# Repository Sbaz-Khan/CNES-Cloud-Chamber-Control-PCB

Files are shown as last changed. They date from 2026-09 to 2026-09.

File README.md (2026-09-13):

# CNES Cloud Chamber Control PCB — ESP32-Based PCB Design

An ongoing **ESP32-based control PCB** developed for the **Concordia Nuclear Engineering Society (CNES) portable diffusion cloud chamber**.

I am serving as the **PCB Design Team Lead** for the project, leading the development of the low-voltage control PCB in **KiCad** and helping translate the overall cloud chamber electronics requirements into a manufacturable board design.

> **Project Status:** In Progress — schematic refinement is nearing completion. Footprint assignment, PCB layout/routing, manufacturing files, and hardware validation are still in development.

---

## Project Overview

A diffusion cloud chamber makes ionizing particle tracks visible by creating a supersaturated alcohol-vapor region above a cooled plate.

The complete CNES system requires several electrical subsystems working together, including:

- Peltier-based cooling
- hot-side and cold-side temperature sensing
- alcohol circulation
- radiator cooling
- chamber illumination
- user controls and display
- electronic regulation of the Peltier cooling stages

The purpose of this project is to develop a **central low-voltage control PCB** that connects these subsystems to an ESP32 and provides the sensing, control, and interface circuitry required by the chamber.

The high-current **24 V Peltier power path remains external to this PCB**. The PCB primarily handles control signals, sensing, user interfaces, and auxiliary 12 V loads.

---

## System Architecture

The cloud chamber uses two main power branches:

- **12 V auxiliary/control branch** — powers the PCB, pumps, fans, LED lighting, and ESP32 power conversion.
- **24 V Peltier branch** — powers two external PSM-292 adjustable buck converters that regulate the two Peltier cooling stages.

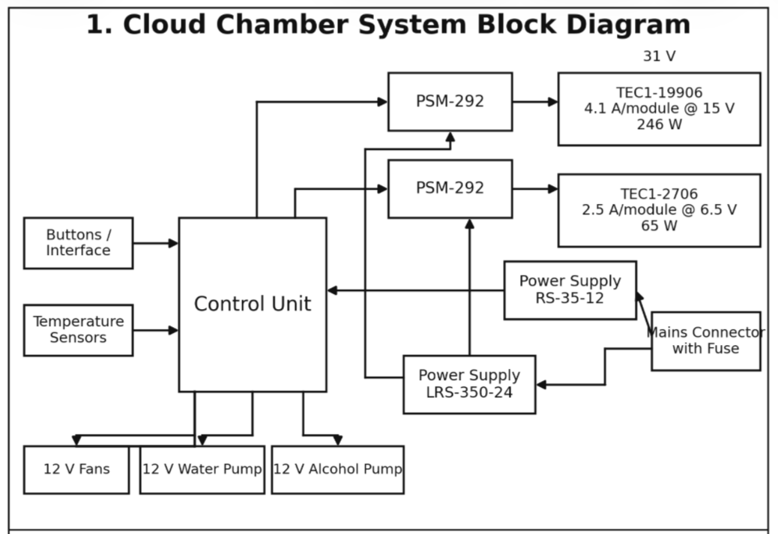
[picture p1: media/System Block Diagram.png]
CNES Cloud Chamber System Block Diagram


*High-level CNES cloud chamber system architecture.*

### Simplified Electrical Architecture

```mermaid
flowchart LR
    AC["Fused / Switched Mains"]

    AC --> PSU12["RS-35-12<br/>12 V Supply"]
    AC --> PSU24["LRS-350-24<br/>24 V Supply"]

    PSU12 --> PCB["ESP32 Control PCB"]
    PSU12 --> AUX["12 V Auxiliary Loads"]

    AUX --> AP["Alcohol Pump"]
    AUX --> WP["Water Pump"]
    AUX --> FANS["Radiator Fans"]
    AUX --> LED["LED Lighting"]

    SENS["Hot & Cold<br/>Thermistors"] --> PCB
    BTN["Start / Reset<br/>Buttons"] --> PCB
    PCB --> OLED["OLED Display"]

    PCB --> DP1["Digital Potentiometer 1"]
    PCB --> DP2["Digital Potentiometer 2"]

    PSU24 --> PSM1["PSM-292 #1"]
    PSU24 --> PSM2["PSM-292 #2"]

    DP1 --> PSM1
    DP2 --> PSM2

    PSM1 --> TEC1["Peltier Stage 1"]
    PSM2 --> TEC2["Peltier Stage 2"]
```

---

## Control Unit Architecture

The ESP32 acts as the central controller for the PCB.

It receives temperature measurements from external thermistors and user inputs from PCB-mounted pushbuttons while controlling or interfacing with the chamber's auxiliary electrical systems.

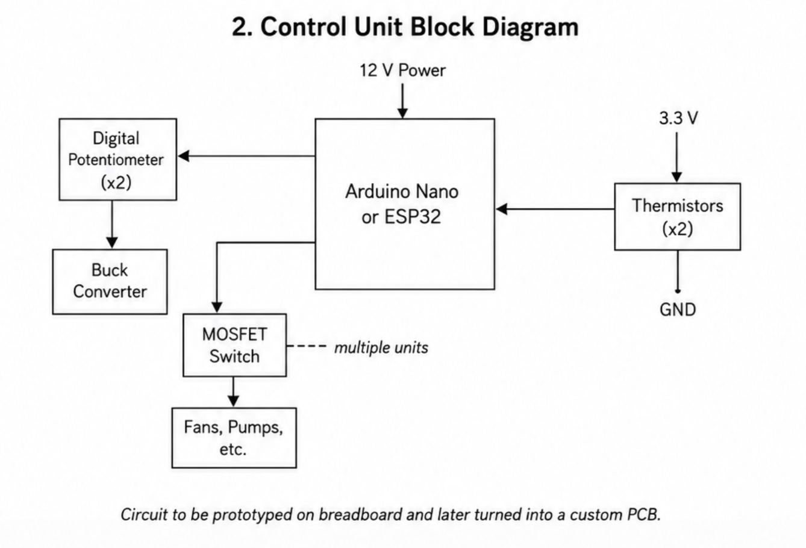
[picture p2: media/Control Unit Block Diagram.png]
CNES Cloud Chamber Control Unit Block Diagram


*Control-unit concept showing sensing, microcontroller control, digital potentiometers, and switched loads.*

---

## PCB Design

The current design uses a **38-pin ESP32 DevKit mounted on two 1×19 headers**, allowing the custom PCB to operate as a carrier/control board.

Using a complete ESP32 DevKit provides built-in:

- USB programming
- voltage regulation
- reset/boot circuitry
- development and debugging support

This reduces implementation risk compared with designing directly around a bare ESP32 device for this prototype.

### Current KiCad Schematic

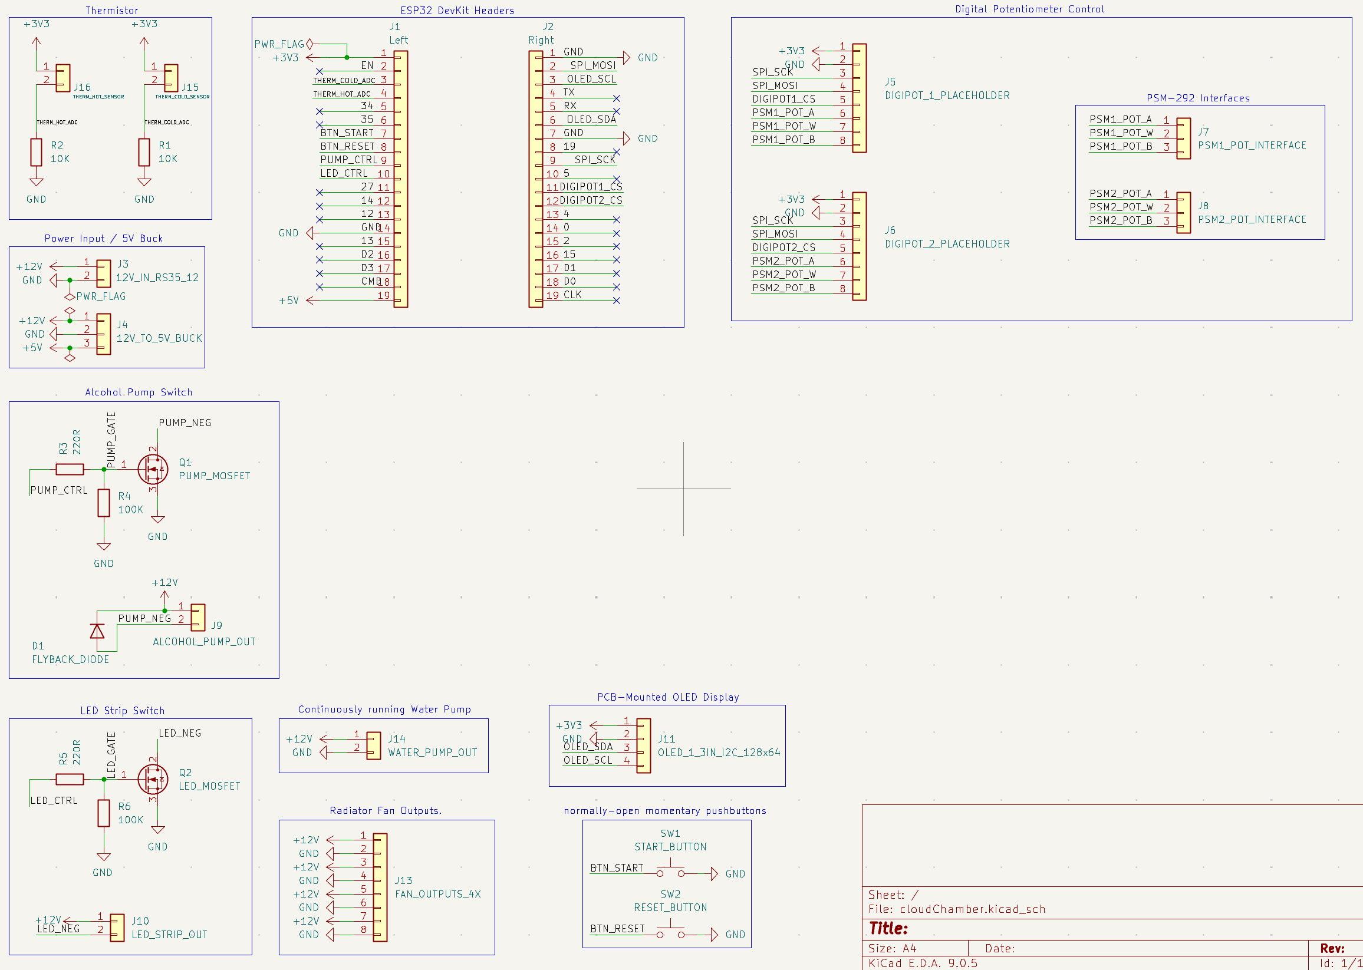
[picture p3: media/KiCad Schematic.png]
CNES Cloud Chamber Control PCB KiCad Schematic


*Current development-stage KiCad schematic for the control PCB.*

---

## Main PCB Subsystems

| Subsystem | Function |
|---|---|
| **ESP32 DevKit Interface** | Central processing and system control |
| **12 V Power Input** | Receives auxiliary power from the RS-35-12 supply |
| **12 V → 5 V Conversion** | Powers the ESP32 DevKit |
| **Thermistor Interfaces** | Measures hot-side and cold-side temperatures |
| **Alcohol Pump Switch** | ESP32-controlled MOSFET switching of the 12 V alcohol pump |
| **LED Strip Switch** | ESP32-controlled MOSFET switching of chamber illumination |
| **Water Pump Output** | Continuous 12 V output for coolant circulation |
| **Radiator Fan Outputs** | Continuous 12 V outputs for radiator cooling fans |
| **OLED Interface** | PCB-mounted I²C display |
| **Pushbuttons** | PCB-mounted Start and Reset controls |
| **PSM-292 Interfaces** | Connections for electronic Peltier-power adjustment |
| **Digital Potentiometer Control** | Planned SPI-based control of the two PSM-292 converters |

---

## Temperature Sensing

Two external **NTC thermistors** are intended to measure:

- cold-side / chamber plate temperature
- hot-side / cooling-system temperature

The physical thermistors are installed at the locations being measured rather than directly on the PCB.

Each thermistor forms a voltage divider with a **10 kΩ fixed resistor** on the control PCB.

```text
+3.3 V
   |
   |
External NTC Thermistor
   |
   +------> ESP32 ADC
   |
 10 kΩ
   |
  GND
```

The ESP32 reads the divider voltage through its ADC and firmware can convert:

```text
ADC Voltage → Thermistor Resistance → Temperature
```

The final thermistor model and temperature-conversion parameters still require confirmation.

---

## Alcohol Pump Control

The 12 V alcohol pump is controlled using a **low-side N-channel MOSFET switch**.

```text
+12 V
  |
Alcohol Pump
  |
  +---- Flyback Diode ----+
  |                       |
MOSFET                     |
  |                       |
 GND ---------------------+
```

The circuit includes:

- logic-level N-channel MOSFET
- 220 Ω gate resistor
- 100 kΩ gate pulldown resistor
- flyback diode for motor inductive transients

The pump is approximately **12 V / 5 W**, corresponding to a nominal current of about:

```text
I = P / V
I = 5 W / 12 V
I ≈ 0.42 A
```

The final MOSFET and flyback-diode part numbers are still being selected.

---

## LED Lighting Control

The chamber lighting is also switched using a low-side N-channel MOSFET controlled by the ESP32.

The LED switching circuit uses:

- logic-level N-channel MOSFET
- 220 Ω gate resistor
- 100 kΩ pulldown resistor

Unlike the alcohol pump, the LED strip does not require a motor flyback diode.

The exact LED strip and its final current requirement are still TBD.

---

## Water Pump & Radiator Cooling

The current design provides continuous 12 V power to:

- the water/coolant circulation pump
- radiator cooling fans

The water pump is currently estimated at approximately **20 W**:

```text
I = 20 W / 12 V
I ≈ 1.67 A
```

Because this is a relatively high-current load for the board, connector type and PCB trace width must be selected accordingly.

The current schematic supports **four 12 V radiator fan outputs**.

---

## OLED & User Controls

The board is designed to support a PCB-mounted:

- **1.3-inch 128×64 I²C OLED**
- **Start button**
- **Reset button**

The buttons are normally-open momentary switches connected between the ESP32 GPIO inputs and ground.

Firmware will use internal pull-ups, giving an active-low interface:

```text
Button Released → HIGH
Button Pressed  → LOW
```

The exact OLED module and mechanical footprint still need to be finalized before PCB layout.

---

## Peltier Power Control

The chamber uses two external **PSM-292 adjustable buck converter modules** to regulate the two Peltier cooling stages.

The planned control architecture is:

```text
ESP32
  |
 SPI
  |
  v
Digital Potentiometer
  |
 A / W / B
  |
  v
PSM-292
  |
  v
Peltier Stage
```

Two digital potentiometer channels are required because the system contains two independently adjustable PSM-292 converters.

The SPI clock and MOSI signals can be shared, while each digital potentiometer uses its own chip-select line.

### Important Design Item

The digital-potentiometer interface is still under development.

Before finalizing this part of the PCB, the following must be verified experimentally:

- original PSM-292 potentiometer resistance
- A/W/B terminal voltages
- terminal current
- compatibility with a digital potentiometer
- safe digital-potentiometer voltage range
- final digital-potentiometer IC
- whether additional protection or interface circuitry is required

The PSM-292 control concept should therefore be considered **planned and under validation**, not finalized.

---

## My Role — PCB Design Team Lead

My responsibility in the CNES cloud chamber project is primarily the development and coordination of the control PCB.

### Contributions to Date

- Leading the PCB design effort for the cloud chamber electronics
- Translating system-level block diagrams and requirements into a KiCad schematic
- Selecting an ESP32 DevKit carrier-board architecture
- Developing the 38-pin ESP32 header and GPIO assignment scheme
- Designing hot-side and cold-side thermistor ADC interfaces
- Designing the alcohol-pump MOSFET switching circuit
- Adding flyback-diode protection for the alcohol pump
- Designing the LED-strip MOSFET switching circuit
- Adding gate resistors and pulldown resistors for controlled MOSFET operation
- Developing 12 V fan and water-pump output interfaces
- Integrating PCB-mounted OLED and pushbutton interfaces
- Developing interfaces for the two external PSM-292 converters
- Planning SPI-controlled digital-potentiometer integration
- Performing KiCad Electrical Rules Checks (ERC)
- Resolving schematic connectivity and power-net warnings
- Coordinating design decisions with the project lead
- Supporting other student team members learning PCB design concepts

The schematic has reached a reported **0 active ERC violations**, although ERC correctness does not replace component compatibility or hardware testing.

---

## Design Development Workflow

The PCB is being developed through the following engineering process:

```mermaid
flowchart LR
    A["System Requirements"] --> B["System Block Diagram"]
    B --> C["Control Architecture"]
    C --> D["KiCad Schematic"]
    D --> E["Component Verification"]
    E --> F["Footprint Assignment"]
    F --> G["PCB Placement"]
    G --> H["Routing"]
    H --> I["DRC + 3D Review"]
    I --> J["Gerber / Manufacturing Files"]
    J --> K["PCB Assembly"]
    K --> L["Hardware Validation"]
```

### Current Position

```text
Requirements
    ↓
Block Diagrams
    ↓
Schematic Design
    ↓
Schematic Refinement      ← CURRENT STAGE
    ↓
Component Selection
    ↓
Footprint Assignment
    ↓
PCB Layout / Routing
    ↓
DRC / 3D Review
    ↓
Gerber Generation
    ↓
Manufacturing
    ↓
Hardware Testing
```

---

## Current Project Status

### Completed / Mostly Completed

- [x] System architecture
- [x] ESP32 DevKit control architecture
- [x] ESP32 GPIO assignments
- [x] thermistor interface circuits
- [x] alcohol pump MOSFET circuit
- [x] LED MOSFET circuit
- [x] water-pump power output
- [x] radiator fan outputs
- [x] OLED interface
- [x] Start / Reset button interface
- [x] PSM-292 A/W/B interface connectors
- [x] schematic ERC cleanup
- [x] 0 active ERC violations at current schematic stage

### In Progress / Remaining

- [ ] finalize digital potentiometer / PSM-292 compatibility
- [ ] select exact digital potentiometer ICs
- [ ] confirm exact ESP32 DevKit mechanical footprint
- [ ] select exact OLED module
- [ ] select final MOSFETs
- [ ] select final flyback diode
- [ ] confirm LED strip specifications
- [ ] confirm radiator fan specifications
- [ ] finalize 12 V → 5 V buck implementation
- [ ] verify complete 12 V system power budget
- [ ] assign PCB footprints
- [ ] perform PCB placement
- [ ] route PCB
- [ ] perform DRC
- [ ] perform 3D mechanical review
- [ ] generate Gerber and drill files
- [ ] prepare BOM / manufacturing files
- [ ] assemble prototype
- [ ] perform hardware validation

---

## PCB Layout Considerations

The upcoming layout stage will include consideration of:

- wider traces for auxiliary 12 V loads
- high-current water-pump routing
- short MOSFET current paths
- flyback diode placement near the pump switching loop
- gate resistors placed close to MOSFET gates
- separation of thermistor analog signals from noisy switching paths
- appropriate connector placement
- ESP32 USB accessibility
- OLED visibility through the enclosure
- pushbutton accessibility
- mechanical mounting holes
- wiring access for pumps, fans, thermistors, and PSM-292 modules
- ground-plane strategy
- enclosure and side-panel clearance

The high-current 24 V Peltier power will **not** be routed through this PCB.

---

## Repository Structure

```text
CNES-Cloud-Chamber-Control-PCB/
│
├── docs/
│   └── Project documentation and design reports
│
├── hardware/
│   └── KiCad schematic and PCB design files
│
├── manufacturing/
│   └── Gerbers, drill files, BOM and fabrication outputs
│
├── firmware/
│   └── ESP32 firmware and control software
│
├── media/
│   ├── KiCad Schematic.png
│   ├── System Block Diagram.png
│   └── Control Unit Block Diagram.png
│
├── README.md
└── .gitignore
```

---

## Tools & Technologies

- **KiCad**
- **ESP32**
- **PCB Design**
- **Schematic Design**
- **Embedded Systems**
- **Power Electronics**
- **Analog Sensor Interfacing**
- **MOSFET Switching**
- **I²C**
- **SPI**
- **Thermistors / ADC Measurement**
- **Git / GitHub**

---

## Planned Hardware Validation

Before a final manufacturing release, critical subsystems will need to be tested and documented.

Planned validation includes:

1. verifying the 12 V and 5 V power paths
2. confirming ESP32 operation
3. checking thermistor ADC measurements
4. testing active-low Start and Reset buttons
5. verifying OLED communication
6. testing alcohol pump switching
7. testing LED switching
8. measuring actual auxiliary-load currents
9. measuring PSM-292 potentiometer terminal characteristics
10. validating the proposed digital-potentiometer replacement
11. checking temperature performance during chamber operation

Measured results will be added to this repository as the project progresses.

---

## Documentation

Detailed design documentation is maintained in the [`docs/`](docs/) directory.

The documentation records:

- design decisions
- subsystem explanations
- electrical calculations
- unresolved design items
- component-selection requirements
- KiCad ERC results
- PCB-layout considerations
- future hardware-validation results

---

## Project Status Notice

This repository documents an **active engineering project**.

The schematic, component selections, PCB layout, and manufacturing outputs may change as testing and design reviews continue.

The PCB has **not yet been manufactured or fully hardware-validated**.

---

## Organization

Developed as part of the **Concordia Nuclear Engineering Society (CNES)** Cloud Chamber project at **Concordia University**.

**Role:** PCB Design Team Lead  
**Focus:** Control PCB architecture, schematic design, subsystem integration, and PCB development

---

## Future Updates

As the project progresses, this repository will be updated with:

- finalized schematic files
- selected component part numbers
- PCB layout
- routed-board screenshots
- KiCad 3D renders
- Gerber files
- BOM
- manufacturing files
- assembled PCB photographs
- test measurements
- cloud chamber integration results

---

*This repository currently represents the schematic-development stage of the CNES Cloud Chamber Control PCB project.*

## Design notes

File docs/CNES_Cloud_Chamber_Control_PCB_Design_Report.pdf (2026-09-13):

# CNES Cloud Chamber Control PCB

### PCB Design Report

Concordia Nuclear Engineering Society Prepared by Sbaz Ali Khan
Design snapshot - 12 September 2026 Revision 0.2

An ESP32 carrier board for temperature sensing, auxiliary load control and the planned electronic adjustment of Peltier power.

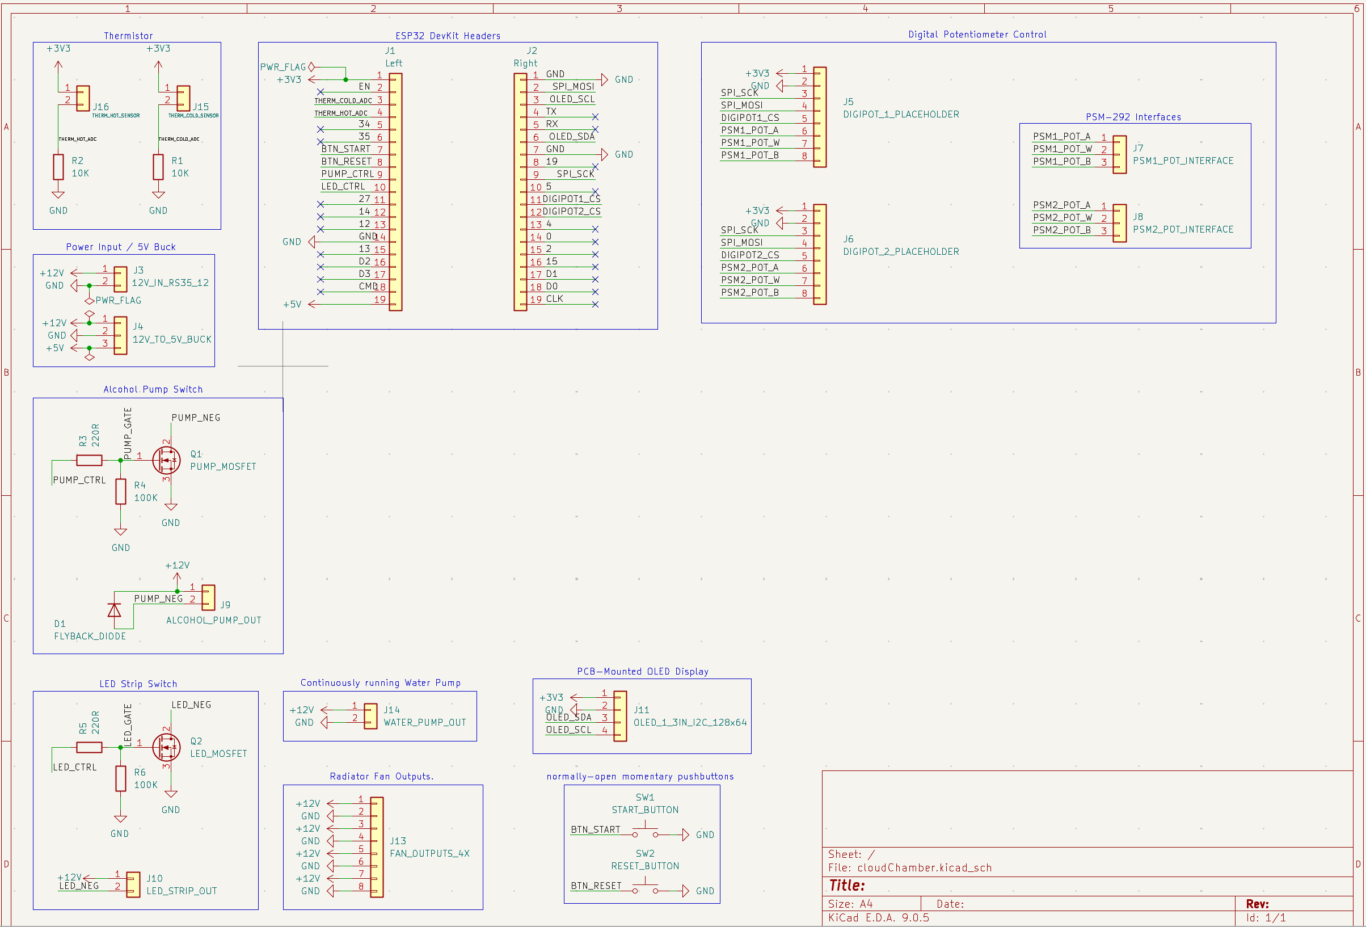
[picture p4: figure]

Current control PCB schematic

Development stage: schematic refinement before footprint assignment and PCB layout.

CNES Control PCB | 12 September 2026

### Table of Contents

# Project objective and current status

The CNES portable diffusion cloud chamber is intended to make ionizing particle tracks visible in supersaturated alcohol vapor above a cooled plate. This work focuses on the development of the low-voltage control PCB that connects temperature sensors, auxiliary loads and the user interface to an ESP32 DevKit.
The current design establishes the carrier-board architecture, pin assignments, thermistor dividers, pump and LED switches, and continuous fan and water-pump outputs. Schematic cleanup reached a reported ERC result of zero active violations. Digital potentiometer compatibility, final component selection, footprint assignment and PCB routing remain to be completed. This report records the design in progress for CNES project continuity and future reference. PCB manufacture and hardware validation remain pending.
The PCB reads hot-side and cold-side temperatures, switches the alcohol pump and bezel lighting, supports an OLED and two buttons, and distributes auxiliary 12 V power. Camera trail classification, permanent count storage and the high voltage clearing field remain broader system functions without finalized implementations on this board. The eventual display requirement includes plate temperature, timer, alpha and beta totals, and counts per minute for each; the initial display focus is cold-plate temperature.
The mains and high-current Peltier paths remain external. The PCB carries auxiliary load current and control signals; it does not route the 24 V Peltier power.

# System architecture

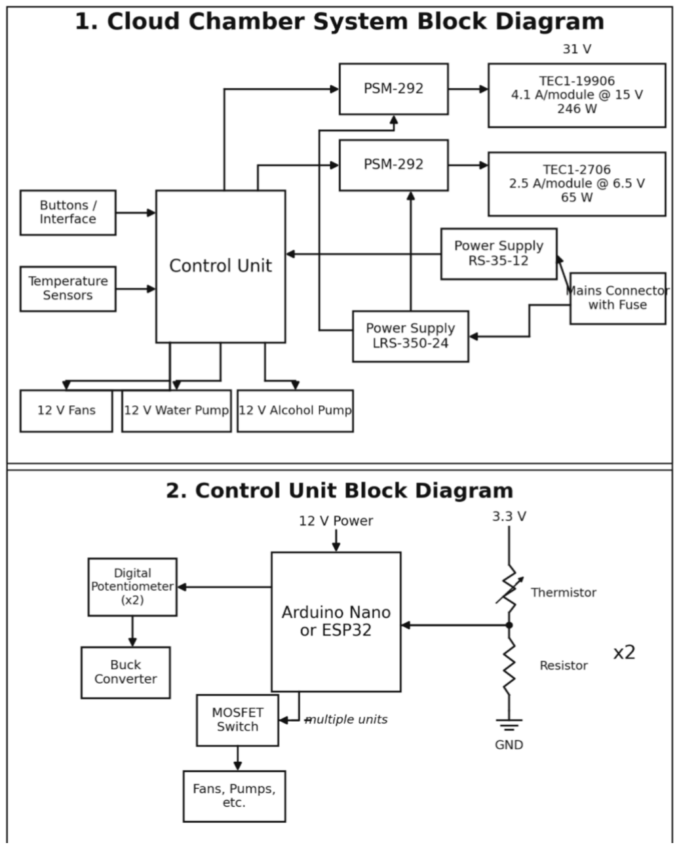
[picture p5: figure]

Figure 1. Overall system block diagram.

The high-level power architecture discussed is:

The fused and switched mains input feeds two separate supplies: the Mean Well RS-35-12 supplies the 12 V auxiliary branch, and the Mean Well LRS-350-24 supplies the 24 V Peltier branch.
The 12 V path powers the control PCB, pumps, fans, LED strip, and a 12 V to 5 V buck stage.
The 24 V path powers the PSM-292 buck converters and Peltier modules. The 24 V / Peltier current is not routed through this PCB.
Known system-level parts from the project/BOM context:
- TEC1-12706 Peltier modules, quantity 4, listed as first-stage Peltier modules
- TEC1-19906 Peltier modules, quantity 4, listed as second-stage Peltier modules
- Mean Well LRS-350-24 power supply, quantity 1, for 24 V Peltier power
- Mean Well RS-35-12 power supply, quantity 1, for 12 V control/auxiliary electronics
- PSM-292 adjustable buck converter modules, quantity 2
- Alcohol pump, 12 V / 5 W, final according to Nathaniel
- Water pump, closer to 20 W according to Nathaniel
- Radiator fans, 120 mm, exact part still not finalized in BOM
- LED strip for bezel, still listed as TBD
- Generic thermistors, quantity 2
- OLED screen and pushbuttons, to be mounted on PCB
- 12 V to 5 V buck converter, exact module/implementation still unresolved

# ESP32 DevKit Header Design

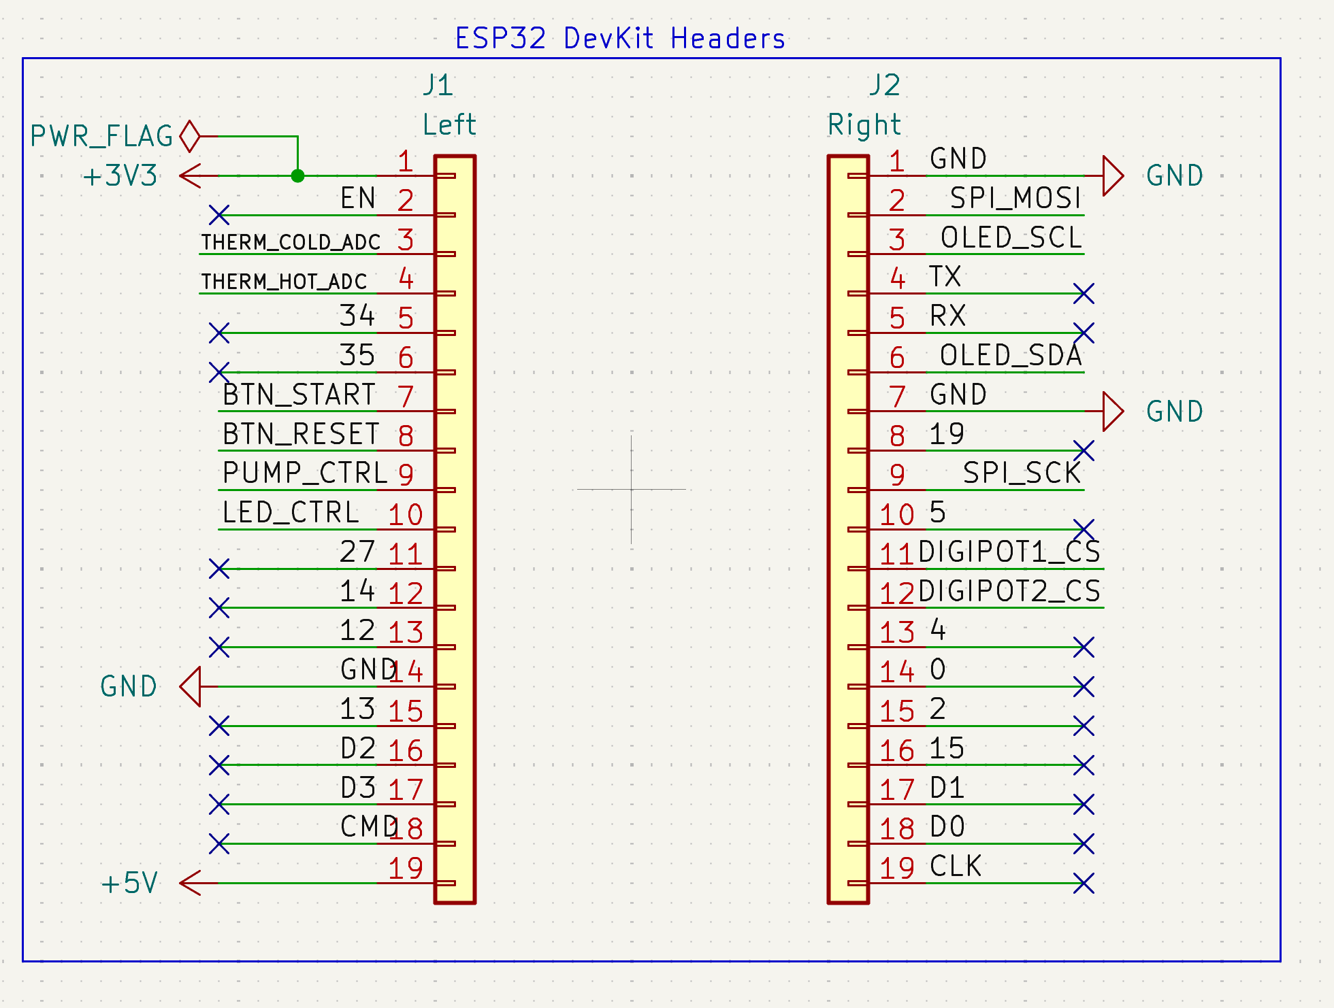
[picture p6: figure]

Figure 2. ESP32 DevKit headers.
The full 38-pin ESP32 DevKit was chosen to reuse its regulator, USB programming, reset and boot support circuits. The carrier uses two 1×19 socket headers; the exact board model, pinout and row spacing must match before layout.
The schematic uses two 1×19 headers:
J1 = ESP32 DevKit left header
J2 = ESP32 DevKit right header
The red numbers in KiCad are connector/header pin numbers. The functional labels correspond to the ESP32 DevKit pinout used during schematic development.

### Used ESP32 pins

ESP32 DevKit pin label | Net name | Function in this PCB
3V3 | +3V3 | 3.3 V logic rail from ESP32 DevKit
5V | +5V | 5 V input to ESP32 DevKit from 12 V to 5 V buck converter
GND | GND | Common ground reference
VP / GPIO36 | THERM_COLD_ADC | Analog ADC input for cold-side thermistor divider
VN / GPIO39 | THERM_HOT_ADC | Analog ADC input for hot-side thermistor divider
GPIO32 | BTN_START | Digital input for start button
GPIO33 | BTN_RESET | Digital input for reset button
GPIO25 | PUMP_CTRL | Digital output controlling alcohol pump MOSFET
GPIO26 | LED_CTRL | Digital output controlling LED strip MOSFET
GPIO21 | OLED_SDA | I2C data line for OLED
GPIO22 | OLED_SCL | I2C clock line for OLED
GPIO23 | SPI_MOSI | SPI data from ESP32 to digital potentiometers
GPIO18 | SPI_SCK | SPI clock for digital potentiometers
GPIO17 | DIGIPOT1_CS | Chip select for digital potentiometer 1
GPIO16 | DIGIPOT2_CS | Chip select for digital potentiometer 2

### Notes on communication pins

GPIO21 and GPIO22 were selected for I2C because they are commonly used as the default ESP32 I2C pins:
GPIO21 = SDA,
GPIO22 = SCL.

The ESP32 can route I2C to other GPIO pins in software, but using the common/default pins keeps the design conventional.
GPIO23 and GPIO18 were selected for SPI:
GPIO23 = MOSI, GPIO18 = SCK.
MISO was not included because the digital potentiometer concept only requires the ESP32 to send commands to the digital potentiometer ICs.
Each digital potentiometer gets its own chip-select line:
DIGIPOT1_CS, DIGIPOT2_CS.
This allows the same MOSI and SCK lines to be shared.

### Unused ESP32 pins

Unused pins were marked with KiCad no-connect flags.
Important pins intentionally avoided:
D0, D1, D2, D3, CMD, CLK: these are typically related to flash memory on ESP32 modules and should not be used for normal project signals.
GPIO0, GPIO2, GPIO12, GPIO15: boot/strapping-sensitive pins, avoided for beginner-safe design. TX and RX: not used because the DevKit handles programming/debug through USB.
EN: not used because the DevKit already has its own enable/reset circuitry.

# Power Architecture

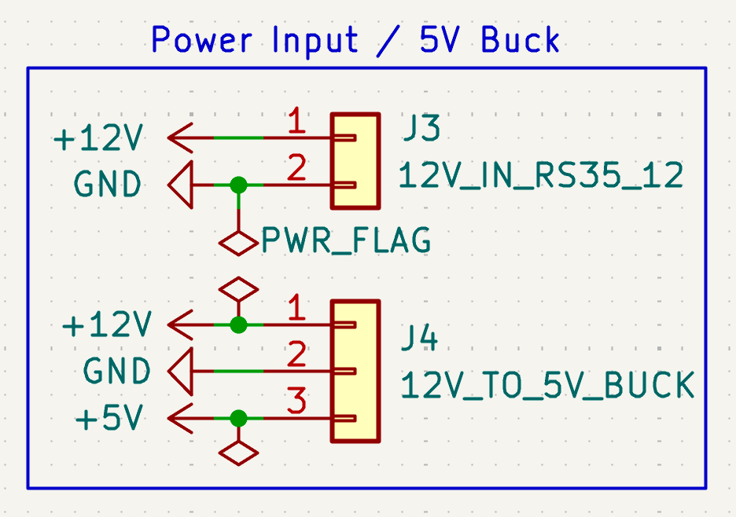
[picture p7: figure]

Figure 3. Power input and 5 V buck stage.

### 12 V input

Connector: J3 = 12V_IN_RS35_12.
Current schematic:
Pin | Net
1 | +12V
2 | GND

This represents the 12 V input from the Mean Well RS-35-12 supply. The RS-35-12 12 V supply powers:
- 12 V to 5 V buck converter
- ESP32 DevKit indirectly through 5 V
- Alcohol pump
- LED strip
- Radiator fans
- Water pump.
Important design concern:
The 12 V supply power budget must be checked once all load currents are finalized. The water pump alone is close to 20 W, or about 1.67 A at 12 V. The alcohol pump is 5 W, or about 0.42 A. Fans, LED strip, and ESP32/buck current must also be included.
Total 12 V current estimate equation:
I_total = I_water_pump + I_alcohol_pump + I_fans + I_LED_strip + I_5V_buck_input
Known calculations:
Alcohol pump: I = P / V = 5 W / 12 V ≈ 0.42 A
Water pump: I = P / V = 20 W / 12 V ≈ 1.67 A.
If the 12 V supply is 3 A, the water pump plus alcohol pump already uses about 2.08 A, leaving limited margin for fans, LED strip, and electronics. This should be checked before final layout.

### 12 V to 5 V buck converter

Connector/block: J4 = 12V_TO_5V_BUCK.
Current schematic:
Pin | Net
1 | +12V
2 | GND
3 | +5V

This represents a buck converter stage that takes 12 V and produces 5 V for the ESP32 DevKit. Unresolved decision:
The buck converter implementation remains to be selected:
a module mounted directly on the PCB or an external buck module wired to the PCB or a fully designed buck converter circuit on the PCB.
This matters because the exact footprint and layout depend heavily on the selected option.

### 3.3 V rail

The ESP32 DevKit provides the +3V3 rail through its onboard regulator.
The PCB uses +3V3 for:
- thermistor dividers
- OLED module logic/power
- digital potentiometer logic, assuming compatible ICs
- possibly other low-voltage logic.
Important constraint:
ESP32 GPIO and ADC pins are 3.3 V logic. Do not apply 5 V or 12 V directly to GPIO/ADC pins.

# Thermistor Subsystem

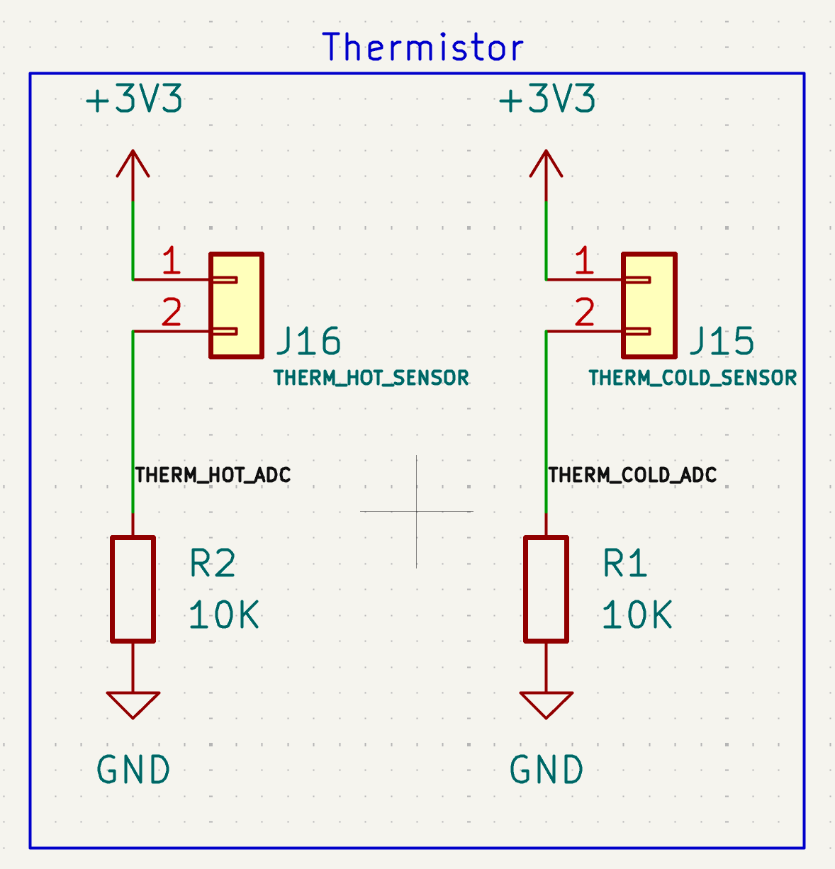
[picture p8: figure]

Figure 4. Thermistor sensor connectors.

### Current revised design

After Nathaniel confirmed the thermistors will be physically mounted on the system, the thermistor symbols were removed and replaced with connectors.
Current connectors:
J15 = THERM_COLD_SENSOR, J16 = THERM_HOT_SENSOR.
Current cold thermistor circuit:
Component/net | Connection
J15 pin 1 | +3V3
J15 pin 2 | THERM_COLD_ADC
R1 | 10 kΩ from THERM_COLD_ADC to GND
ESP32 pin | VP / GPIO36 reads THERM_COLD_ADC

Current hot thermistor circuit:

Component/net | Connection
J16 pin 1 | +3V3
J16 pin 2 | THERM_HOT_ADC
R2 | 10 kΩ from THERM_HOT_ADC to GND
ESP32 pin | VN / GPIO39 reads THERM_HOT_ADC

### Rationale

The ESP32 cannot directly read resistance. It reads voltage on ADC pins.
A thermistor changes resistance with temperature. With the voltage divider, the temperature-dependent resistance becomes a temperature-dependent voltage.
For the current topology:
+3.3 V → external NTC thermistor → ADC node → 10 kΩ resistor → GND
Voltage divider equation:
V_ADC = 3.3 V × R_fixed / (R_NTC + R_fixed)
With R_NTC = 10 kΩ and R_fixed = 10 kΩ:
V_ADC = 3.3 V × 10k / (10k + 10k) = 1.65 V
For a 10 kΩ NTC thermistor:
temperature increases → thermistor resistance decreases → ADC voltage increases temperature decreases → thermistor resistance increases → ADC voltage decreases.
The ESP32 ADC reads the voltage. Firmware then converts:
ADC voltage → thermistor resistance → temperature
The thermistor conversion requires the thermistor’s resistance curve, beta value, or lookup table. The exact thermistor beta value is still unresolved.

# Alcohol Pump MOSFET Switch

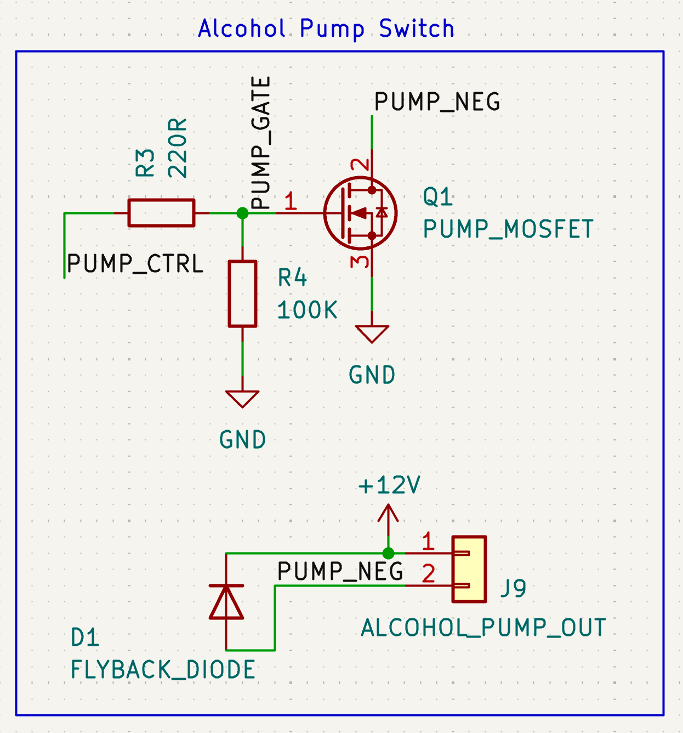
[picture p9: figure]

Figure 5. Alcohol pump MOSFET switch.
The alcohol pump requires on and off control only. No direction reversal is required, so an H-bridge is unnecessary.

### Purpose

The alcohol pump needs to be controlled by the ESP32. The ESP32 GPIO cannot power the pump directly, so a MOSFET switch is used.
The alcohol pump is confirmed as approximately:
12 V, 5 W, current ≈ 0.42 A.
Calculation:
I = P / V = 5 W / 12 V ≈ 0.42 A

### Current schematic

Main components:
Q1 = PUMP_MOSFET
R3 = 220 Ω and R4 = 100 kΩ D1 = FLYBACK_DIODE
J9 = ALCOHOL_PUMP_OUT.
Connector:
J9 pin | Net
1 | +12V
2 | PUMP_NEG

MOSFET connections:

MOSFET terminal | Connection
Gate | PUMP_GATE
Drain | PUMP_NEG
Source | GND

Control signal:
ESP32 GPIO25 → PUMP_CTRL → R3 220 Ω → PUMP_GATE Pulldown:
PUMP_GATE → R4 100 kΩ → GND
Flyback diode:
Diode side | Connection
Cathode/bar side | +12V
Anode side | PUMP_NEG

### Operating principle

This is a low-side N-channel MOSFET switch.
“Low-side” means the MOSFET is placed between the load and ground:
+12V → pump → MOSFET → GND
When PUMP_CTRL is LOW:
gate voltage ≈ 0 V à MOSFET is off àdrain-source path is open, so pump negative side is not connected to ground and pump is off.
When PUMP_CTRL is HIGH:
ESP32 drives gate to approximately 3.3 V à MOSFET turns on and drain-source path conducts so pump negative side connects to ground and current flows through the pump à pump turns on.

### Gate resistor

R3 = 220 Ω
Purpose:
- limits the sudden current spike into the MOSFET gate
- reduces ringing/noise
- limits transient gate-charging current at the ESP32 GPIO
- makes switching cleaner.
The MOSFET gate behaves somewhat like a small capacitor, so the gate resistor slows the sudden charge/discharge slightly.

### Pulldown resistor

R4 = 100 kΩ
Purpose:
- keeps the MOSFET gate at 0 V when ESP32 is booting, resetting, or not actively driving the pin
- provides the intended default-off bias.
The pulldown is called “weak” because 100 kΩ is a large resistance. It gently pulls the gate to ground, but when the ESP32 drives the gate high, the ESP32 easily overrides it.
Default state:
gate = 0 V → MOSFET off

### Flyback diode

The alcohol pump is a motor/inductive load. When switched off, the motor current cannot stop instantly and can create a voltage spike at PUMP_NEG.
The flyback diode gives the leftover motor current a safe loop path.
Normal operation:
+12V side is high and PUMP_NEG side is near ground when MOSFET is on, so the diode is reverse-biased/off.
When the MOSFET turns off:
pump tries to keep current flowing and the PUMP_NEG can spike upward à diode turns on once PUMP_NEG rises above the +12 V side by about a diode drop à current safely circulates through pump and diode à the diode limits the turn-off transient.
The selected diode and MOSFET ratings still require verification.
Important correction made during discussion:
In this low-side switch, the dangerous spike at PUMP_NEG is usually a positive spike, not a negative spike.

# LED Strip MOSFET Switch

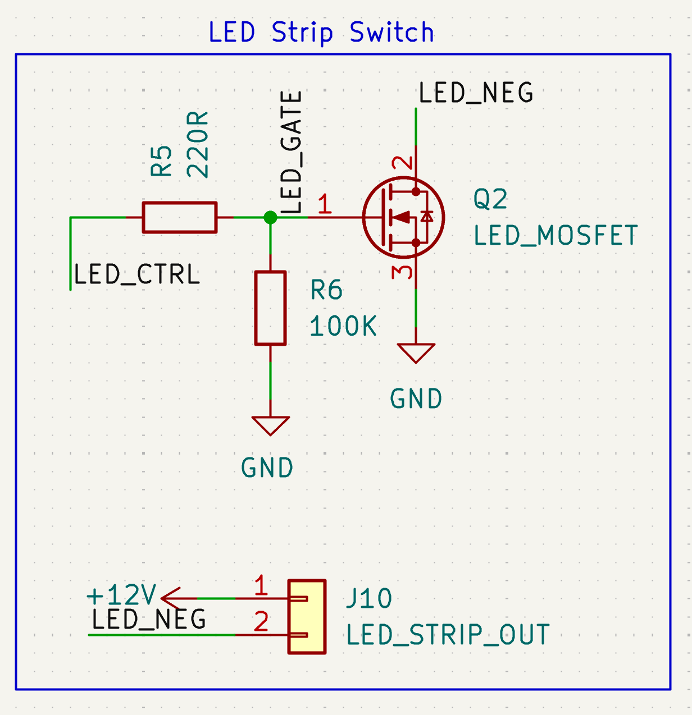
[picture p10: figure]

Figure 6. LED strip MOSFET switch.

### Purpose

The LED strip is controlled by the ESP32 using a MOSFET switch.
The LED strip is intended to illuminate the chamber, so particle tracks are visible.

### Current schematic

Main components:
Q2 = LED_MOSFET, R5 = 220 Ω, R6 = 100 kΩ, J10 = LED_STRIP_OUT. Connector:
J10 pin | Net
1 | +12V
2 | LED_NEG

MOSFET connections:

MOSFET terminal | Connection
Gate | LED_GATE
Drain | LED_NEG
Source | GND

Control signal:
ESP32 GPIO26 → LED_CTRL → R5 220 Ω → LED_GATE Pulldown:
LED_GATE → R6 100 kΩ → GND

### Operating principle

Same as the alcohol pump switch, but without the flyback diode.
When LED_CTRL is LOW:
MOSFET off à LED negative side not connected to ground à LED strip off.

When LED_CTRL is HIGH:
MOSFET gate ≈ 3.3 à MOSFET on à LED negative side connects to ground à current flows: +12V → LED strip → MOSFET → GND à LED strip on.

### Why no flyback diode

The LED strip is not a motor/inductive load, so it does not require a flyback diode like the pump.

# MOSFET Selection Requirements

The schematic currently uses generic N-channel MOSFET symbols for Q1 and Q2.
These are not final part numbers.
The final MOSFETs must be:
N-channel, logic-level, fully enhanced with 3.3 V gate drive, rated for the load current with margin, rated for at least the relevant voltage, preferably 30 V or more for 12 V loads and low RDS(on) at VGS = 2.5 V or VGS = 3.3 V.
Important clarification:
VGS (th) is not enough. Gate threshold voltage only means the MOSFET barely starts to turn on. It does not mean the MOSFET can carry the load current efficiently.
Need to check:
RDS (on) specified at low gate voltage.
RDS (on) means drain-source resistance when the MOSFET is on. Lower RDS (on) means less heat. MOSFET heat estimate:
P_MOSFET ≈ I² × RDS (on)
This will be useful when choosing the final MOSFETs after load currents are known.

# Water Pump Output

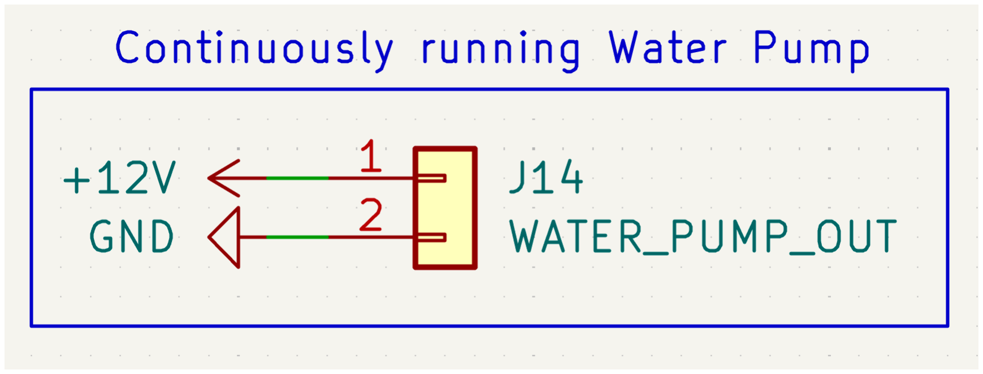
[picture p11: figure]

Figure 7. Continuous water pump output.

### Purpose

The water pump circulates coolant/water in the hot-side cooling loop. It is not for putting water into the chamber.
The water loop carries heat away from the hot side of the Peltier modules to the radiator.

### Current design

Current decision: water pump runs continuously.
Connector:
J14 = WATER_PUMP_OUT.
Current schematic:
J14 pin | Net
1 | +12V
2 | GND

No MOSFET control is used for the water pump.

### Power and current

Nathaniel stated the water pump draws closer to 20 W.
At 12 V: I = 20 W / 12 V ≈ 1.67 A
Based on Nathaniel’s rule, this should use a screw terminal because it is above 1 A.

# Radiator Fan Outputs

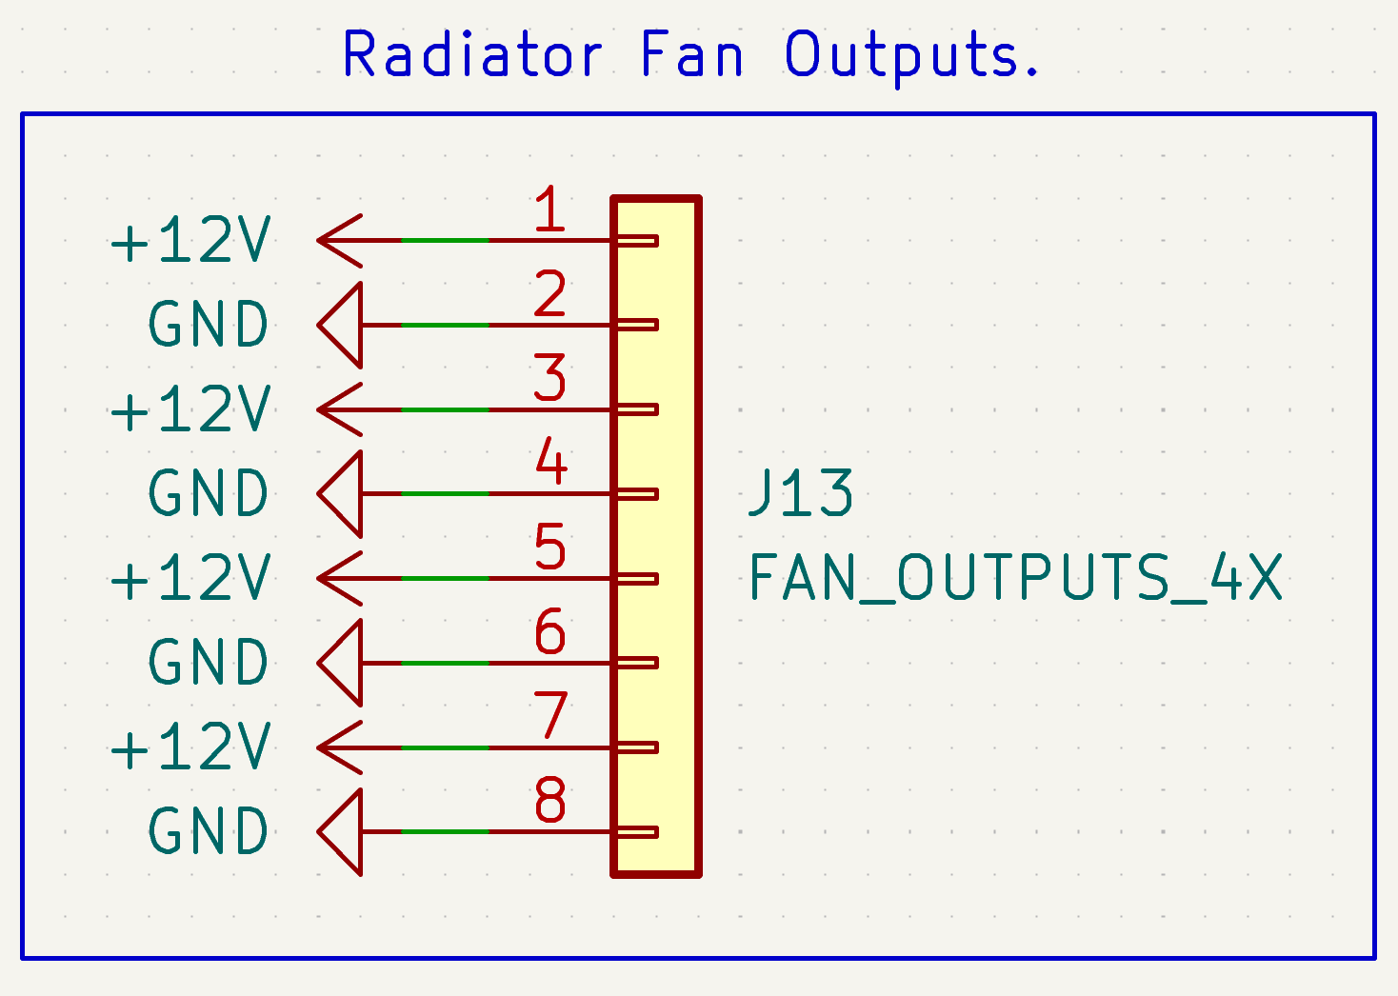
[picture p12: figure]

Figure 8. Radiator fan outputs.

### Purpose

Fans cool the radiator. The water loop carries heat from the Peltier hot side to the radiator, and fans blow air through the radiator to dump that heat into room air.
Cooling chain:
Heat passes from the cold plate through the Peltier stack into the water block. The water pump circulates coolant to the radiator, where the fans reject heat to ambient air.

### Current schematic

Connector:
J13 = FAN_OUTPUTS_4X.
Current schematic supports four 12 V fan outputs:
Fan | Pins
Fan 1 | pin 1 = +12V, pin 2 = GND
Fan 2 | pin 3 = +12V, pin 4 = GND
Fan 3 | pin 5 = +12V, pin 6 = GND
Fan 4 | pin 7 = +12V, pin 8 = GND

Current decision: fans run continuously from 12 V.
No MOSFET control is included for fans.

# OLED Display Subsystem

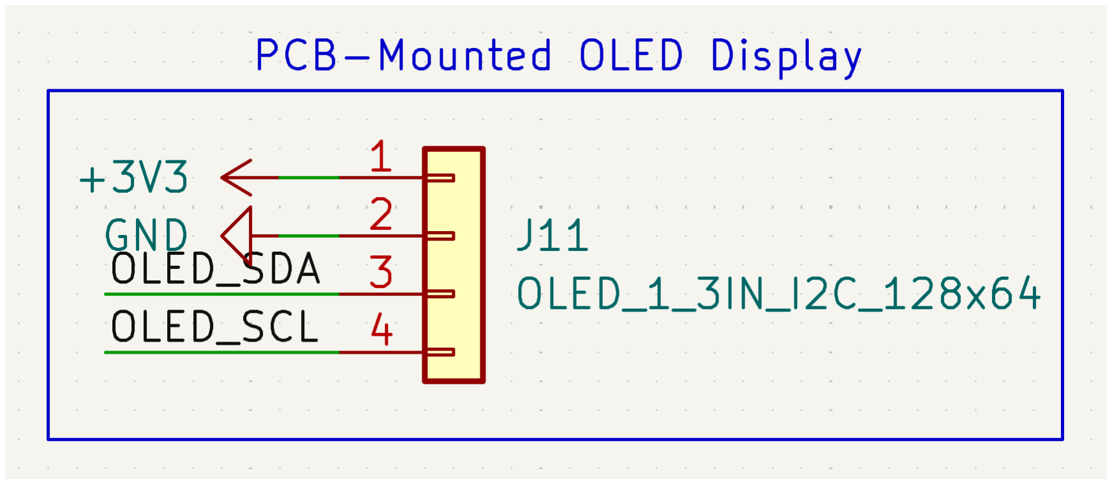
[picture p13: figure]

Figure 9. PCB mounted OLED interface.

### Revised design

Nathaniel said the PCB is mounted on one of the side panels, so the OLED and buttons can be directly on the PCB. The OLED design was updated to be PCB-mounted.
Current connector/module interface:
J11 = OLED_1_3IN_I2C_128x64.
Current schematic:
J11 pin | Net
1 | +3V3
2 | GND
3 | OLED_SDA
4 | OLED_SCL

The schematic block was renamed:
PCB-Mounted OLED Display.

### OLED selection direction

A 2-inch OLED was considered, but concern was raised that larger OLEDs are more likely to use SPI or have more complex pinouts. To minimize schematic changes and keep the design simple, the direction was changed back to:
1.3-inch; 128×64 pixels; I2C interface; 4-pin module; 3.3 V-compatible.
Reason:
1.3-inch 128×64 I2C OLED modules are common and fit the current simple 4-wire design.

### Important OLED warning

The electrical schematic can remain as 4 pins, but the exact OLED module must be selected before layout because modules may differ in:
pin order, module board size, mounting hole spacing, header orientation, voltage requirement, I2C vs SPI interface etc.
Some modules may order pins as VCC, GND, SCL, SDA instead of VCC, GND, SDA, SCL. The final footprint must match the actual module.

### Assembly note

PCB-mounted does not automatically mean the manufacturer will solder the OLED module during PCB fabrication.
There are two cases:
Bare PCB order: OLED is soldered/mounted manually later
PCBA order: manufacturer assembles it only if the part/module is included and supported. This decision is still not finalized.

# Button Subsystem

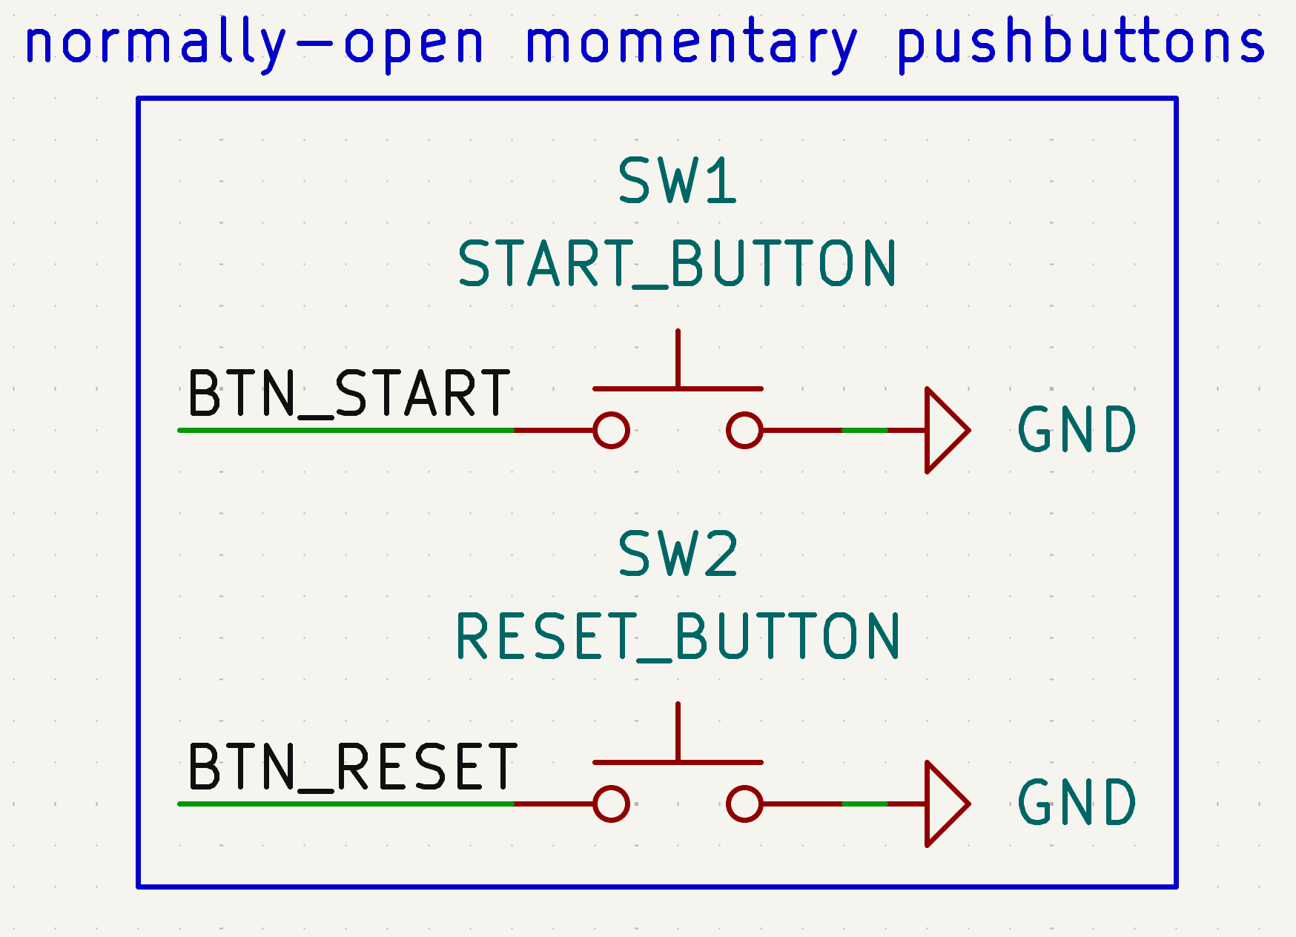
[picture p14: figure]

Figure 10. Start and reset buttons.
BTN_RESET is an application input on GPIO33, not a hardware connection to the ESP32 EN pin. Its reset action must be defined in firmware.

### Revised design

After Nathaniel confirmed OLED/buttons can be PCB-mounted, J12 was replaced with two real switch symbols.
Current design:
SW1 = START_BUTTON and SW2 = RESET_BUTTON.
Both are normally-open momentary pushbuttons.
Current wiring:
Button | Connection
SW1 START_BUTTON | BTN_START to GND
SW2 RESET_BUTTON | BTN_RESET to GND

### Operating principle

The ESP32 will use internal pull-up resistors in firmware.
Button not pressed:
switch open à ESP32 pin is pulled HIGH internally à code reads HIGH. Button pressed:
switch closes à signal connects to ground à ESP32 reads LOW.
This is an active-low button configuration.

# Digital Potentiometer PSM-292 Control Subsystem

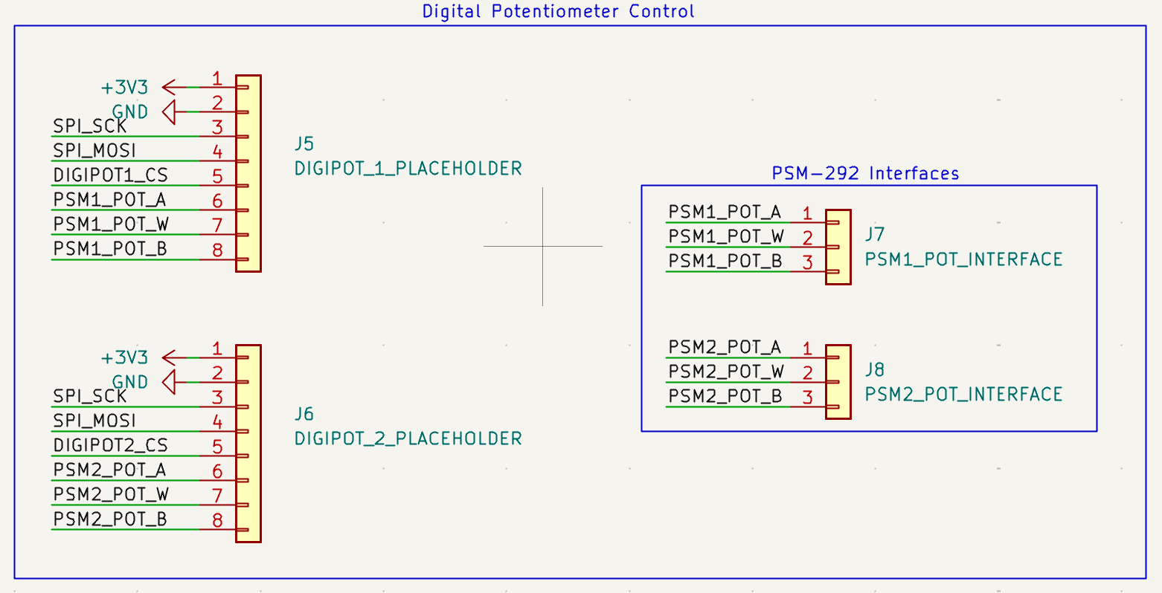
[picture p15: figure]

Figure 11. Digital potentiometer and PSM 292 interface.
Compatibility with the PSM-292 adjustment circuit is the main unresolved schematic dependency.

### Purpose

The project uses two PSM-292 adjustable buck converter modules. These control the output voltage going to Peltier stages/groups.

The PSM-292 modules normally use manual potentiometers to adjust output voltage.
The design idea is to electronically replace or interface with those manual potentiometers using digital potentiometer ICs controlled by the ESP32.

### Important correction

The PSM-292 itself does not understand SPI.
The digital potentiometer IC understands SPI.
Correct control chain:
ESP32 → SPI → digital potentiometer IC → A/W/B terminals → PSM-292 potentiometer pads → converter output voltage → Peltier cooling power.

### Current placeholder design

Current schematic placeholders:
J5 = DIGIPOT_1_PLACEHOLDER and J6 = DIGIPOT_2_PLACEHOLDER. Each has 8 pins:
Pin | Function
1 | +3V3
2 | GND
3 | SPI_SCK
4 | SPI_MOSI
5 | DIGIPOTx_CS
6 | PSMx_POT_A
7 | PSMx_POT_W
8 | PSMx_POT_B

Where:
J5 uses DIGIPOT1_CS, PSM1_POT_A/W/B and J6 uses DIGIPOT2_CS, PSM2_POT_A/W/B.

### Proposed next schematic revision

It was later recognized that J5 and J6 should probably not remain as external 8-pin connectors. Proposed direction, pending IC selection and compatibility testing:
Replace J5 with actual digital potentiometer IC symbol, likely U2 and replace J6 with actual digital potentiometer IC symbol, likely U3.
Then:
SPI lines remain internal PCB traces; A/W/B outputs go to external PSM-292 interface connectors.

### PSM-292 interface connectors

Current connectors:
J7 = PSM1_POT_INTERFACE and J8 = PSM2_POT_INTERFACE. Each has three pins:
Pin | Net
1 | PSMx_POT_A
2 | PSMx_POT_W
3 | PSMx_POT_B

These are intended to connect from the control PCB to the physical PSM-292 module’s potentiometer pads.
These are signal/control connections, not high-current Peltier power connections.

### Why two digital potentiometers

There are two PSM-292 modules. Each module needs its own electronic potentiometer control. Therefore:
digital potentiometer 1 controls PSM-292 #1 and digital potentiometer 2 controls PSM-292 #2.
The SPI clock and MOSI lines are shared. Each digital potentiometer has a separate chip-select pin.

### Critical unresolved technical checks

Before finalizing the digital potentiometer ICs, the following must be confirmed or measured:
- Resistance value of the original PSM-292 manual potentiometer
- Voltage range on the PSM-292 potentiometer terminals A/W/B
- Current through the potentiometer terminals
- Whether the manual potentiometer can be safely removed/desoldered
- Whether a digital potentiometer can directly replace it
- Whether one PSM-292 should be tested first before final PCB design
- Exact digital potentiometer IC part number
- Whether the digital potentiometer terminals can tolerate the PSM-292 voltage range. Important safety/design constraint:
Many digital potentiometers powered at 3.3 V can only tolerate terminal voltages between GND and VDD. If the PSM-292 potentiometer terminals exceed 0–3.3 V, a normal 3.3 V digital potentiometer could be damaged.

### Considered IC family

A Microchip MCP41xxx/MCP42xxx-style SPI digital potentiometer family was mentioned as a possible direction, but no IC was finalized.
Do not treat any digital potentiometer IC as selected yet.

# Connector Strategy

Nathaniel provided a general connector rule: loads under 1 A → pin headers acceptable loads higher than 1 A → screw terminals.

### Current connector implications

Interface | Current expectation
ESP32 DevKit headers | 1×19 female headers, exact spacing required
Alcohol pump output | likely pin header, because 0.42 A
Water pump output | screw terminal, because about 1.67 A

Interface | Current expectation
Fan outputs | likely pin headers if each fan is under 1 A; exact fan current still needed
LED strip output | depends on final LED strip current
Thermistor connectors | small pin headers or JST-style connectors; tiny current
PSM-292 A/W/B interface | small pin header or JST-style connector; signal-level wiring
12 V input J3 | likely screw terminal because it carries total 12 V system current
OLED module | module header/footprint matching selected OLED
Pushbuttons | actual PCB-mounted button footprints, not connector
Buck converter J4 | depends on whether module is onboard, external, or fully designed on PCB

### Pin header clarification

When Nathaniel says, “pin headers,” he most likely means common 2.54 mm header pins, usually male pins soldered to the PCB with a female cable connector on the wire side.
However, pin header can technically mean either male or female. The exact choice must be made during footprint assignment.
For the ESP32 DevKit, the PCB likely needs female socket headers, so the DevKit plugs into the PCB.

# Electrical rule check notes

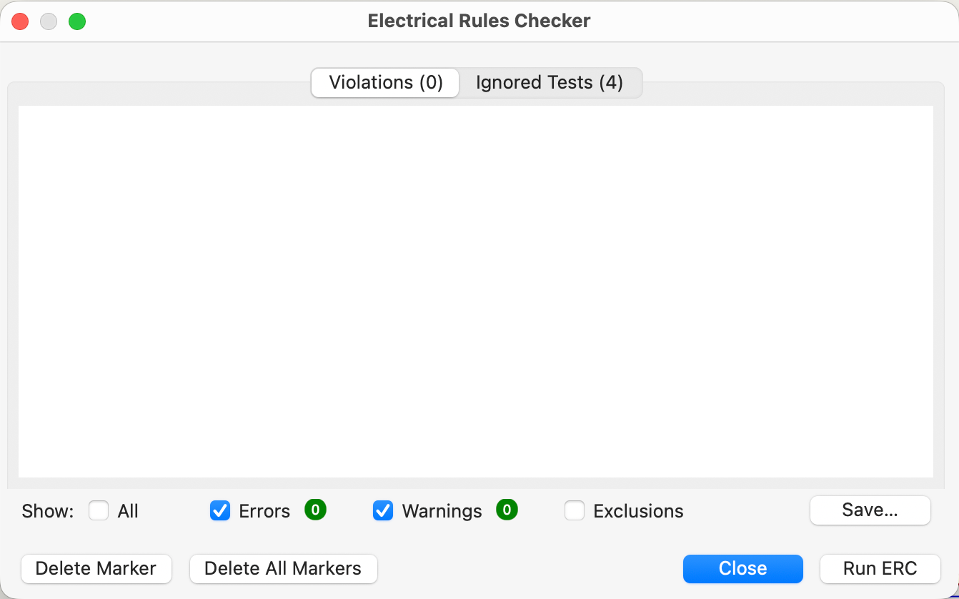
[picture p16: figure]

Figure 12. Electrical rule check result.
ERC was run during schematic cleanup. Issues encountered and resolved:

### Duplicate net names

Example:
+5V power symbol and 5V net label on the same wire. KiCad warning:
both +5V and 5V attached to the same item.
Fix:
remove extra 5V net label and keep +5V power symbol.
Similar cleanup applied to extra labels like VP and VN when they were placed as net labels on the same wires as THERM_COLD_ADC and THERM_HOT_ADC.
Important distinction:
pin names built into the symbol can remain
duplicate net labels placed on wires should be removed.

### Unconnected wire endpoints

Some warnings were caused by wires or labels appearing visually connected but not actually snapped to the pin/wire grid.
Fix:
move symbols or labels so wires snap properly, re-run ERC.

### Power input not driven

KiCad complained:
“Input Power pin not driven by any Output Power pins”
Reason:
KiCad saw power nets like +12V, +5V, +3V3, and GND, but generic connectors do not automatically tell KiCad that a real supply is driving those nets.
Fix:
add PWR_FLAG symbols on the real power rails: +12V; +5V; +3V3; GND.

### No-connect flags

No-connect flags were placed on unused ESP32 pins.
Important rule established:
Do not place no-connect flags on pins that are used through net labels. For used signal pins like SPI_MOSI, OLED_SCL, OLED_SDA, SPI_SCK, DIGIPOT1_CS, and DIGIPOT2_CS, the correct fix is proper net-label connection, not no-connect flags.

### Reported ERC result

After fixes, ERC showed:
0 violations; 0 errors; 0 warnings.
Ignored tests were present. Review their scope when rerunning ERC, a clean ERC result does not establish component compatibility or hardware performance.

# Design decision record

### Confirmed design direction

- Use ESP32 DevKit carrier-board approach, not bare ESP32 chip.
- Use 38-pin ESP32 DevKit layout with two 1×19 headers.
- Use ESP32 ADC pins VP/GPIO36 and VN/GPIO39 for thermistor voltages.
- Use GPIO25 for alcohol pump MOSFET control.
- Use GPIO26 for LED strip MOSFET control.
- Use GPIO21/GPIO22 for I2C OLED.
- Use GPIO23/GPIO18 for SPI MOSI/SCK.
- Use GPIO17/GPIO16 as chip selects for the two digital potentiometers.
- Alcohol pump controlled by low-side N-channel MOSFET.
- LED strip controlled by low-side N-channel MOSFET.
- Water pump runs continuously from 12 V.
- Radiator fans run continuously from 12 V.
- Thermistors are mounted physically on the system, not directly on the PCB.
- Fixed 10 kΩ thermistor divider resistors remain on PCB.
- Buttons are PCB-mounted normally-open momentary pushbuttons.
- OLED is PCB-mounted, likely 1.3-inch 128×64 I2C module.
- Loads under 1 A can use pin headers; loads above 1 A should use screw terminals.

### Considered but rejected or changed

- Bare ESP32 chip/module: rejected in favor of full ESP32 DevKit.
- External OLED/buttons via connector only: changed after Nathaniel said OLED/buttons can be on PCB side panel.
- Thermistors directly on PCB: changed because thermistors must measure actual physical hot/cold locations.
- 2-inch OLED: considered but moved away from because larger OLED modules may use SPI or more complex pinouts. 1.3-inch I2C retained as the working target; the exact module is still unconfirmed.
- J5/J6 as external digital potentiometer connectors: recognized as probably not final. They should likely become actual digital potentiometer ICs on the PCB.
- Water pump MOSFET control: not included for now; water pump is continuous.

- Fan MOSFET control: not included for now; fans are continuous.

# Open items before release

Resolve these items before committing the affected footprints, routing or manufacturing release.

### ESP32 DevKit

Confirm the exact 38-pin DevKit model, electrical pinout and mechanical dimensions.
Required details:
row-to-row spacing; pin pitch; USB port location and clearance; board outline etc.

### OLED

Need exact OLED module selection.
Current target:
1.3-inch; 128×64; I2C; 3.3 V-compatible; PCB-mounted.
Need confirm:
exact module dimensions; pin order; footprint/header spacing; mounting holes; side-panel cutout size.

### LED strip

Still TBD.
Need:
voltage; current or wattage; physical connector/wire style; whether it is 12 V; length/brightness requirement; whether it should be switched only on/off or dimmed with PWM.

### Radiator fans

Need final fan part number and quantity.
Current schematic supports 4 fan outputs. BOM screenshots have shown inconsistent/unclear fan quantity/part status.
Need:
exact 120 mm fan part; voltage; current per fan; connector style; final fan quantity.

### Digital potentiometer and PSM 292

Major unresolved item.
Need:
original PSM-292 potentiometer resistance value; terminal voltages on A/W/B; terminal current; confirmation that manual pot can be removed/desoldered; test result showing digital pot replacement works; exact digital potentiometer IC; whether digital pot terminal voltage range is safe; footprint/package for the digital potentiometer IC, whether any extra buffering/protection/isolation is needed.

### Buck converter

Need exact decision:
onboard module; external module; or full onboard buck circuit. Need exact part if module-based.
The footprint for J4 cannot be finalized until this is known.

### 12 V power budget

Need final current values for:
water pump; alcohol pump; fans; LED strip; buck converter input current; ESP32/OLED/digital pot consumption.
Then verify RS-35-12 supply can handle total load with margin.

### Final parts still to choose

Not yet finalized:
logic-level N-channel MOSFETs for pump and LED; flyback diode for alcohol pump; exact connector footprints; pushbutton footprints; resistor package sizes; thermistor model, connector style; digital potentiometer ICs; OLED module footprint; ESP32 DevKit header footprints and spacing; buck converter footprint/implementation.

# Next steps and PCB layout

The project is still pre-layout. Remaining work:

### Finalize schematic changes

Still required:
replace J5/J6 digital potentiometer placeholders with real IC symbols once selected; keep J7/J8 as PSM-292 interface connectors; update LED strip once final part/rating is known; update fan outputs if final fan count differs from current 4-output design; update buck converter block once exact implementation is chosen.

### Assign footprints

Need footprint assignment for:
ESP32 DevKit 1×19 female headers; OLED module/header; SW1/SW2 pushbuttons; J3 12 V input connector; J4 buck converter/module interface; J7/J8 PSM-292 potentiometer interfaces; J9 alcohol pump output; J10 LED strip output; J13 fan outputs; J14 water pump output; J15/J16 thermistor connectors; MOSFETs Q1/Q2; flyback diode D1; resistors R1/R2/R3/R4/R5/R6; PWR_FLAG symbols do not need physical footprints.

### Board placement planning

Nathaniel suggested:
OLED and buttons on one side of PCB facing the user/side panel cutout; microcontroller, connectors, and chips on the other side of PCB.
Layout must account for:
side-panel cutouts; OLED visibility; button accessibility; ESP32 USB access; wire routing to pumps/fans/thermistors/PSM modules; connector accessibility; mechanical mounting holes; enclosure clearance.

### Routing considerations

Important layout considerations:
- Use wider traces for 12 V load currents.
- Water pump trace must handle about 1.67 A plus margin.
- 12 V input trace may carry total system auxiliary current and should be sized accordingly.

- Keep MOSFET current paths short and wide.
- Place flyback diode close to the pump connector/MOSFET loop.
- Place gate resistors near MOSFET gates.
- Place pulldown resistors near MOSFET gates.
- Keep analog thermistor traces away from noisy high-current switching paths where possible.
- Use ground pours if appropriate.
- Ensure common ground between ESP32 control board and relevant control electronics.
- Do not route high-current Peltier power through this PCB.
- Run DRC after routing.
- Check 3D viewer for connector orientation, side placement, OLED position, and ESP32 fit.

### Manufacturing outputs still needed

After layout:
DRC clean; silkscreen labels checked; connector pin labels visible where useful; Gerber files; drill files; BOM; pick-and-place file if PCBA is used; assembly notes; 3D view screenshot for review; final review with project lead before ordering.

# Design calculations and verification plan

The existing numerical work comprises the thermistor divider midpoint and nominal pump-current estimates. These support early component and power planning; trace widths, MOSFET dissipation and full supply loading are not yet finalized.

Calculation | Current value | Meaning
Alcohol pump | 5 W / 12 V ≈ 0.42 A | Nominal estimate: startup current remains to be checked.
Water pump | 20 W / 12 V ≈ 1.67 A | Approximate load; rating needs confirmation.
Combined pumps | 25 W / 12 V ≈ 2.08 A | Calculated from unrounded inputs. The earlier 2.09 A figure sums rounded values.
Divider midpoint | 3.3 V × 10 / (10 + 10) = 1.65 V | Equal 10 kΩ thermistor and fixed resistor.
MOSFET conduction loss | P ≈ I² × RDS (on) | No final result until parts and load currents are known.

The 10 kΩ divider is the current schematic choice. Equal resistance gives a midpoint output. Sensitivity and useful ADC range at the actual hot and cold operating temperatures still need validation with the selected thermistor curve. The handoff’s conditional 3 A supply example is a planning assumption, not a verified supply rating.

### Planned hardware validation

The electronics requirements call for collecting parts and breadboard testing before PCB manufacture. Record the PSM-292 potentiometer measurements and replacement test first. Then verify regulated rails, thermistor readings, active-low buttons, OLED operation and pump and LED switching. Add actual load currents, startup behavior and measured temperatures as results become available. No completed bench-validation result is recorded here.

### Maintaining the design record

Maintain this report alongside the PCB. For each resolved item, record the selected part, rationale, schematic revision and supporting measurement. Preserve earlier decisions as history. Add routed PCB views, assembly photographs and test results when available. Date each screenshot and test result so CNES can identify the design revision it represents.

Revision | Date | Change
0.2 | 12 September 2026 | Clearer development status and document maintenance guidance.
[Next] | [Date] | [Record schematic, layout or test changes]

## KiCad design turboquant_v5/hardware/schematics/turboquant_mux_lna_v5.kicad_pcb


Board: 4 copper layers, 100.0 x 80.0 mm, 25 parts (0 on the bottom side), 3 nets.

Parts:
F1: 2A; Fuse_1206_3216Metric
J1: 12V_Input; TerminalBlock_bornier-2_P5.08mm
J2: TX_BUS; SMA_EDGE
J3: E1_GPIO; PinHeader_2x10_P2.54mm_Vertical
J4: RX0_OUT; SMA_EDGE
J5: RX1_OUT; SMA_EDGE
Q9, Q10, Q11, Q12, Q13, Q14, Q15, Q16: IRF830; TO-220-3_Vertical
U1: LM7805; TO-252-2
U2: AMS1117-3.3; SOT-223-3_TabPin2
U3, U4: DG408; SOIC-16_3.9x9.9mm_P1.27mm
U5: 74HCT595; SOIC-16_3.9x9.9mm_P1.27mm
U6, U7: OPA1641; SOIC-8_3.9x4.9mm_P1.27mm
U8, U9, U10, U11: TC4427; SOIC-8_3.9x4.9mm_P1.27mm

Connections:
+5V: U1.3, U2.3
+12V: F1.1, F1.2, J1.1, U1.1
GND: J1.2, J2.2, J4.2, J5.2, U1.2, U2.1
